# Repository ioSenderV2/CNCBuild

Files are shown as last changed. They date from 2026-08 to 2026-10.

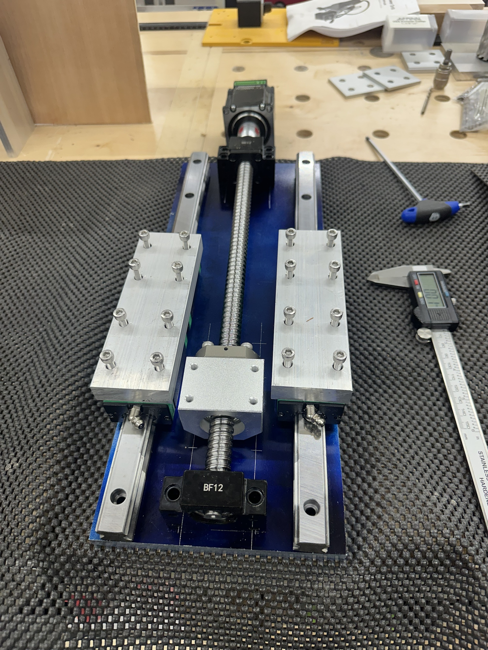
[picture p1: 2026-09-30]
machine/photos/z-carriage-assembly-end.jpg

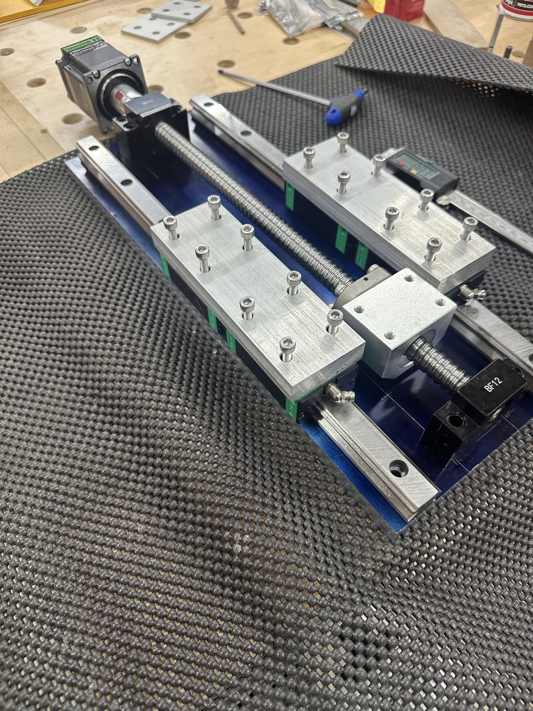
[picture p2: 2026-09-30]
machine/photos/z-carriage-assembly-oblique.jpg

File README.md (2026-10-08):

# CNCBuild

The machine, and everything about building, wiring, configuring and instrumenting it. Gantry beams are
**stacked pairs of 8020 `30-6060`** on HGR20 rails and 1605 ball screws.

Written down because these facts kept getting re-derived in conversation - travels, plate dimensions,
what shares a drag chain, which stored setting disagreed with the machine. A firmware fork's scratch
folder was the wrong home for them.

| Folder | What is in it |
|---|---|
| [`machine/`](machine/) | The build itself: extrusions, rails, screws, plates, and the mechanical decisions with their reasons |
| [`linear-encoder/`](linear-encoder/) | Magnetic linear scales + AS5311 + ESP32-S3 → CAN → grblHAL. The most developed subsystem; design complete, nothing built |
| [`commissioning/`](commissioning/) | Measurements taken **from the machine** - travels, squaring, tape extents. The authority when the config disagrees |
| [`wiring/`](wiring/) | How the boxes connect - the DB37 between the controller box and the remote axis breakout box |

## Generated views - regenerate, never edit

Three files are built from the prose rather than maintained beside it, because a
hand-maintained summary drifts from what it summarises. That is not hypothetical here: on
2026-10-02 two settled decisions were relitigated, both because a pointer had gone stale.

| Build it with | What you get |
|---|---|
| `python tools/status.py all` | [`STATUS.md`](STATUS.md) - every open item, harvested from the ✅ ⚠️ 🔴 ❌ markers in the prose. [`INDEX.md`](INDEX.md) - every heading in the repo |
| `tools\make-pdf.ps1` | **`build-document.pdf`** - the whole mechanical design as one printable file: the thirteen `machine/*.md` files in reading order, a clickable contents, all fifteen photographs embedded with their captions, and links into the shop pack. ~4.4 MB, 97 pages. **Untracked** - rebuild it, do not commit it |

**If a generated file and a `.md` file disagree, the `.md` file wins** and the generated copy
is stale. The PDF needs two packages - `python -m pip install markdown pillow` - the first to
render the prose, the second to scale the photographs to print size on the way in (22.9 MB of
originals become 4.4 MB of PDF, still over 300 dpi at the size they are printed; the originals
in `machine/photos/` are never touched). `status.py` is stdlib-only on purpose, because it
gates correctness and the PDF does not.

## What lives elsewhere

| | Where | Why |
|---|---|---|
| grblHAL firmware + the CAN plugin | `stevenrwood/iMXRT1062`, branch `srw/local-build-config` | It is firmware and needs that build tree |
| ioSender (the sender application) | `ioSenderV2/ioSender` | Its own product |

## A standing rule for this repo

**The machine is the authority, not the configuration.** `$130` once read 889 mm against a real 860 mm,
because a catalog preset overwrote a measured value - which quietly cost soft-limit protection until it
was found by accident. Anything in `commissioning/` is measured; anything quoted from a config file is
labelled as such.

Datasheets are **committed, not linked**. The ESP32 module's header pinout was extracted once, lost, and
had to be recovered from a schematic - and both of that vendor's URLs refuse a plain fetch. A link is not
a copy.

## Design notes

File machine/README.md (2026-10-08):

# The machine

The build itself: extrusions, rails, screws, plates, and the mechanical decisions with their reasons.
Measured values belong in [`../commissioning/`](../commissioning/).

## 🔴 Two documents, split by register - read this first

**[`assembly.md`](assembly.md) says what gets built. The thirteen chapters say why.** Keep them apart.
A page that carries both is arguing with itself while somebody is holding a drill, which is how one
unusable document came about in the first place.

| | Source | Printout | What belongs in it |
|---|---|---|---|
| **The build document** | [`assembly.md`](assembly.md) | `build-document.pdf`, ~18 pages | Parts, hardware, what bolts to what, in the order it is done. Imperative. No reasoning, no options weighed, no figure's history |
| **The design record** | the thirteen chapters below | `design-record.pdf`, ~102 pages | Why the machine is that shape. The schemes that were tried and killed, the figures that moved and when, every ⚠️ and 📌. Reference, never worked from |

📋 **`tools\make-pdf.ps1`** from the repo root builds both. `-Doc build` or `-Doc record` for one.
Both are derived and untracked: **if either disagrees with a `.md` file, the `.md` file wins.**

🔴 **A new decision goes in a chapter, and then into `assembly.md` if it changes what gets built.**
Writing the reasoning into `assembly.md` is the failure this split exists to prevent.

| File | What is in it |
|---|---|
| [`assembly.md`](assembly.md) | **How the machine goes together.** Every part, its hardware, and the order of work - mill trip, beams, Y ends, X gantry, Z, spindle, stand-and-measure, box, sand |
| [`gantry-beam-joint.md`](gantry-beam-joint.md) | Each gantry beam is two stacked 8020 `30-6060`. How they are tied together, and the four schemes that were killed getting there |
| [`torsion-box.md`](torsion-box.md) | What the machine stands on. The box, its three cedar posts, the base frame and shear walls, and the transport plan |
| **The ten plate files** | What holds the beams up and what hangs off them — listed below |
| [`drawings/`](drawings/) | **Derived, not authoritative.** The shop pack for the machining trip - one sheet per plate, printable to PDF. If a sheet and a file above disagree, **the file wins** |

## The plates, risers and the spindle mount

**Partly settled.** The beams themselves are finished — see
[`gantry-beam-joint.md`](gantry-beam-joint.md). These ten files cover what holds them up and what
hangs off them. Several dimensions are still **⚠️ Open** and are marked as such rather than guessed;
[`open-items.md`](open-items.md) is the generated-adjacent list of them, and the repo-wide one is
[`../STATUS.md`](../STATUS.md).

They were one 2877-line file, `end-plates-risers-and-spindle.md`, until 2026-10-02. The split is
verbatim — no decision was reopened in the move — and it is along the seams the prose already had.

📋 **These thirteen are the design record**, printed by `tools\make-pdf.ps1` as
`design-record.pdf` — in reading order, with a clickable contents and every photograph embedded
beside the chapter that cites it. **To carry something to the machine, carry `build-document.pdf`
instead** — see the two-document note at the top of this file.

| File | What is in it |
|---|---|
| [`loads-and-plate-thicknesses.md`](loads-and-plate-thicknesses.md) | **Read this first.** The cutting-force recalibration (500-1000 N, not 250) that **every deflection figure in this repo depends on**, the plate and riser thicknesses it sets, and the one measurement that would settle the 1/4" question |
| [`y-beam-support.md`](y-beam-support.md) | How each Y beam is held at its ends: the end plate / Z riser, the **cast stepper frames** on all four axes, the thrust block, the inverted ball nut and its sole plate, and BF12 at the rear |
| [`lateral-stiffness.md`](lateral-stiffness.md) | The lateral fix — tapered front fins per beam, the **one 1210.73 mm steel back plate** replacing both rear risers and the shear panel, and the tongues that back them |
| [`outboard-plate.md`](outboard-plate.md) | The full-height outboard plate: **10 gauge steel**, also the Y back joining plate, how it lands on the torsion box, the galvanic cost, and the encoder tape that runs on the front plate |
| [`spindle-and-mount.md`](spindle-and-mount.md) | The Ø80 2.2 kW water-cooled spindle, its body dimensions, why not 3 kW, and the 109 mm offset from the X beam to its centreline |
| [`stepper-sizing.md`](stepper-sizing.md) | **2.2 N·m NEMA 23 on all four axes**, and why neither 1.5 nor 3.2 — thrust is a non-term on a 5 mm lead, the screw and the rotor are the inertia, and the real ceiling is the **measured 930 mm** span's whip at 1510 rpm |
| [`z-carriage.md`](z-carriage.md) | The 164 × 175 × 1/2" Z plate, the spacer blocks and why they get skimmed, the clamp mount geometry, the travel budget and the top stop |
| [`x-gantry-end-plates.md`](x-gantry-end-plates.md) | The two X gantry end plates: the vertical stack-up, the 242.5 mm height, the sole plate and doubler block, the four bolts above the Y beam top, and the shelf |
| [`tramming.md`](tramming.md) | Roll by **shimming the shelf**, nod still open, and why the carriage plate joint is deliberately not adjustable |
| [`machining.md`](machining.md) | **One trip, so design ahead of the build.** One WCS origin per plate, one reference rail, and what mating hardware to take |
| [`open-items.md`](open-items.md) | Everything still unmeasured, grouped by where it came from |

## Frame and motion

| | |
|---|---|
| Beams, all three axes | **Two 8020 `30-6060` stacked** — 60 mm wide × 120 mm tall, **1000 mm** long |
| Rails | **HGR20**, one per profile, 17 × M5 at 60 mm into T-nuts. **Y rails are on the beams' inside faces, facing each other.** X, Y1 and Y2 share one kit; **Z is a 400 mm kit from a different supplier** - do not quote one kit's dimension for the other |
| Bearing blocks | **77.09 mm** each, measured - two butted read **154.18 mm**, which is what sets the 154 mm plate width. Of that, only the **51.15 mm machined pad** bears; a butted pair spans **128.24 mm** of pad, and that is the real floor for any carriage plate |
| Ball screws | **1605**. **Every axis drives through a cast stepper frame** — X, Y1, Y2 and Z — carrying motor face, bearing housing and coupler in one part, which is what retired the M5 standoffs. BF12 stays at each far end. Y ball nuts run **inverted**, on a tongue off the bottom of the carriage plate, so their bolts are reachable at assembly |
| Ball screw position | **X on top** (preserves vertical milling height); **both Y underneath** (Y1's top must stay clear for the X stepper) |
| Y steppers | **At the FRONT of the machine** (2026-10-02) — one cast frame carries motor face, bearing housing and coupler |
| Steppers | **2.2 N·m, NEMA 23, on X, Y1, Y2 and Z** — one type, so one spare covers every axis. Not 3.2: no thrust is needed and a higher-inductance motor in the same frame is worse above ~1200 rpm, which is where the rapids live. See [`stepper-sizing.md`](stepper-sizing.md) |
| Y beams | **Do not move** — their end plates bolt to the torsion box |
| Y axis assembly mass | **37 lb** each, before the joining plates |
| Spindle | **Ø80 mm, 2.2 kW water-cooled** with matching VFD, on two 80 mm clamps |
| Y beam support | **Front:** a tapered 100→200 mm × 302 mm × 1/2" plate per beam, with a 60.5 × 50 window for the stepper frame. **Rear:** one **1210.73 mm × 12" × 1/4" A36 steel** plate for both beams. Ends only — the ball screw runs under the beam |
| **Plate height** | 🔴 **The five plates that stand on the box are all 301.625 (11 7/8") high** — two side plates, the back plate, two front fins — and **every hole on them is measured from the bottom edge**, the edge that bears on the box's top skin. One height plus one reference edge is what lines the beam up without any plate knowing about another. **A part that is not 301.625 is misordered or mismade.** PLATE_H in the registry; the other three symbols derive from it so they cannot drift |
| Plate materials | 6061 throughout **except** the two Y outboard plates (**10 gauge steel**) and the Y rear plate (**1/4" A36**) — see [`loads-and-plate-thicknesses.md`](loads-and-plate-thicknesses.md), [`outboard-plate.md`](outboard-plate.md) and [`lateral-stiffness.md`](lateral-stiffness.md) |

**Axes:** X, plus a ganged **Y1 (Y) / Y2 (A)** pair, plus Z. `Y_GANGED` + `Y_AUTO_SQUARE` in the
firmware config, so the second Y motor is M3.

### End plates

Partly specified - see [`y-beam-support.md`](y-beam-support.md) and
[`lateral-stiffness.md`](lateral-stiffness.md). They bolt the Y beams to the torsion box.

🔴 **Reworked 2026-10-02 and all four as-built Y risers are scrapped.** Cast stepper frames replaced
BK12 and the M5 standoffs, the Y steppers moved to the front, and the two rear risers became one
1210.73 mm steel plate that is also the rear shear panel. Four measurements gate cuts that cannot be
undone — see [`open-items.md`](open-items.md) before ordering or cutting anything for the Y ends.

**Deferred, not blocking: the 35 mm sensor bore.**
[`../linear-encoder/design-can-position-feedback.md`](../linear-encoder/design-can-position-feedback.md)
§ "The sensor mount" reads as though each endplate and the X gantry plate **already has a 35 mm
hole**. That was written against plates that existed; on this build **nothing has been drilled**.

So it is not a conflict to resolve - it is simply a **feature to include when these plates are
designed**, and the encoder design's wording will want a light touch once they are. Carry it as an
input to the end plate design, not as an open question.

## Cable routing

The two gantry-end encoder cables run **inside the extrusion**, then through the **drag chain** -
which also carries **the spindle cable** and the stepper cables.

**The spindle cable is the first thing to move if anything looks wrong.** A VFD lead is the worst
emitter on the machine and in the chain it runs parallel to the encoder cables for their whole
length. The route is already chosen: overhead, with the coolant and air lines. This is written down
because the failure signature is counts drifting over hours, which reads exactly like lost steps and
sends you to the mechanics instead of the cable.

Drag chain brackets bolt **through the back joining plate** into T-nuts in the outer slots - see
[`gantry-beam-joint.md`](gantry-beam-joint.md).

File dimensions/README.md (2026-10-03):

# Dimensions

**A convention change, made deliberately on 2026-10-02, and a bigger one than the drawings folder.**

[`registry.toml`](registry.toml) is **authoritative for values.** The `machine/*.md` files stay
authoritative for **reasoning**. If a number here and a number in prose disagree, **this folder wins
and the prose is stale.**

That inverts the previous rule, under which the `.md` files were the source of truth for everything.
It is a narrower inversion than it sounds: the registry owns only *what a number is*, and prose keeps
owning *why* — what it trades against, what was rejected, what it would cost to change. Nothing about
how the files read has to change.

## Why

On 2026-10-02 a single session found **five wrong numbers** in the prose. They were two different
faults, and only one of them is fixed by writing numbers down in one place.

**Three were bad primitives carried as labels.** A "5/8in" spacer that measured **16.41**; a
"Φ80×200" spindle whose nameplate reads **213**; a "1/2in" plate whose stock is **10 mm**. In every
case the repo had recorded what the part was *sold as* and then used it as a dimension.

**Two were orphaned derivations**, and these are the dangerous class:

| | |
|---|---|
| The shelf's rear bolt | dimensioned from the **beam front**. The beam moved to flush; the hole did not, and it now lands at Y 0 — off the edge of the plate |
| "1.8 mm proud" | computed from an M8 column at **20**. The column was corrected to 35 elsewhere in the same file, and the consequence was left behind |

**A symbol would not have caught either.** A number in prose is just text; nothing checks it. What
catches them is the **reverse index** — change a primitive, and the tool lists every value that has
to be re-derived. That is what `expr` is for and why the registry is machine-readable rather than a
markdown table.

## Use

Run through [`../tools/dims.py`](../tools/dims.py). Stdlib only, Python 3.11+.

| Command | |
|---|---|
| `dims.py check` | evaluate everything; non-zero exit on any error. Also lists what is **not confirmed on the real part** |
| `dims.py deps SYM` | **what depends on SYM, transitively. Run this BEFORE changing a primitive** |
| `dims.py open` | every OPEN or nominal value, and what each feeds |
| `dims.py table` | every symbol, value, provenance |
| `dims.py fusion` | Fusion 360 parameters CSV |
| `dims.py md` | regenerate [`VALUES.md`](VALUES.md) |

## Provenance is not decoration

It is the repo's standing rule — *the machine is the authority, not the configuration* — made
machine-readable.

| | |
|---|---|
| `measured` | off the real machine or part, with an instrument |
| `part` | off a part's own geometry that is not in doubt |
| `vendor` | off a datasheet committed to `manufacturer-assets/` |
| `nominal` | ⚠️ a catalogue figure **not yet confirmed on the part** — the class that produced three of this session's five errors |
| `derived` | computed here from other symbols |
| `OPEN` | 🔴 not established. **A placeholder. Must not be cut to.** |

## Fusion

`dims.py fusion` writes [`fusion-parameters.csv`](fusion-parameters.csv) for **Modify → Change
Parameters → Import**.

⚠️ **Verify the first import rather than trusting it.** Fusion has shipped variations on whether it
wants a header row; `--header` adds one if yours does.

🔴 **Every symbol exports as a plain number, never as its expression.** Fusion would accept the
expression, but then two systems would own the same derivation and they would drift — which is the
exact failure this registry exists to stop. **The registry derives; Fusion consumes.** Re-export and
re-import after any registry change, because Fusion holds a copy and a copy goes stale.

## What this does not do yet

⚠️ **Nothing enforces that a number quoted in prose matches the registry.** `deps` tells you what to
go and check; it does not check it for you. A prose checker — tagging quoted numbers so they can be
verified mechanically — is the obvious next step and is **not built**.

⚠️ **Only the ten plate files split out of `end-plates-risers-and-spindle.md` on 2026-10-02
have been mined for primitives** - see [`../machine/README.md`](../machine/README.md) for the list.
The other `machine/*.md` files have numbers that are not in here.
Key them in as they get touched rather than attempting a sweep, which is the version of this job that
gets abandoned half-done.

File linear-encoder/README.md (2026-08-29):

# Linear scale position feedback

Magnetic linear scales on each axis, read by AS5311 sensors, decoded to positions by an ESP32-S3, sent
over CAN to the Teensy, so grblHAL knows where each axis **actually** is. Status: **design only, nothing
built.**

| File | What it is |
|---|---|
| **[`design-can-position-feedback.md`](design-can-position-feedback.md)** | **Start here.** The whole design: scope, the sensors, the machine's layout, staleness, the CAN frame, grblHAL integration, failure modes, phasing, and the wiring (§14). |
| [`controller-board.md`](controller-board.md) | The 4-jack daughter board that sits over the ESP32 module: the no-magnetics rule, the mechanical envelope, and the 5 mm-pin / 14 mm-standoff problem. |
| [`sensor-board.md`](sensor-board.md) | The AS5311 board in the puck: what goes on each face, the passives, and the connector question the layout is waiting on. |
| [`hardware-esp32-s3-rs485-can.md`](hardware-esp32-s3-rs485-can.md) | The ESP32 module's 20-pin header map - **not documented on the Waveshare wiki**, only in the schematic. |
| [`kicad/controller-board/`](kicad/controller-board/) | KiCad project. Schematic drawn and verified against KiCad 10.0.5; **no layout yet**, and the symbols are placeholders to be swapped for real parts. |
| [`kicad/sensor-board/`](kicad/sensor-board/) | KiCad project. Schematic drawn and verified the same way; **no layout yet**, and the connector footprint is deliberately unresolved (see `sensor-board.md`). |
| [`../manufacturer-assets/`](../manufacturer-assets/index.html) | The AS5311 datasheet (rev 1.12) and the module schematic. **Untracked** - third-party documents in a public repo. The tracked `index.html` there records where each came from, including the browser-User-Agent trick both waveshare.com URLs need. |

The datasheets are **kept on disk on purpose**: the header map was extracted once, lost, and had to be
found again. A link is not a copy - but nor is someone else's document ours to republish, so the files
stay untracked and `../manufacturer-assets/index.html` records how to fetch each one.

## What is not here yet

- **Both PCB layouts.** Two schematics exist and both pass ERC, but nothing has been placed or routed,
  and every symbol is still a placeholder carrying the netlist rather than a real part.
- **The ESP32-S3 firmware**, and the grblHAL plugin at the other end of the CAN link.
- **The puck-mount mechanical drawings** - the 35 mm round, the 30 mm bore, and the anti-rotation
  fix that §1.4 leaves open.

An earlier note here said that when the first of these landed the work would probably want its own
repo, away from the firmware fork. That has happened: this **is** that repo.

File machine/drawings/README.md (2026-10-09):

# Drawings

**This folder is a convention change, made on purpose on 2026-09-30.**

Until now this repo had no drawings. The premise was that **the reasoning is the artifact** - prose
that says *why* a dimension is what it is survives a redesign, where a drawing does not. That premise
still holds for everything in `machine/*.md`, and those files remain the **source of truth**.

What forced the addition is the **one machining trip**. Prose cannot be taken to a mill. Two things in
particular are hard to carry in words and easy to get wrong later - the **riser geometry** and the
**three-point pad layout relative to the five legs** - and that was already flagged as a decision to
make deliberately rather than drift into.

## The rules this folder follows

- **Derived, never authoritative.** If a sheet and a `.md` file disagree, **the `.md` file wins** and
  the sheet is stale. Nothing is specified here for the first time.
- **Hand-authored SVG, inline in one HTML file.** No CAD dependency, no binary blobs, and it diffs.
  Print to PDF from a browser when a paper copy is wanted - the same route the Mega-XL build doc in
  the ioSender repo uses.
- **Unknowns are marked, never invented.** Amber rows are dimensions that do not exist anywhere in the
  repo. That is the repo's standing rule applied to drawings: an unknown stays unknown until it is
  measured.
- **One WCS origin per plate, absolute coordinates, never chained.** The mill is manual in X and Y, so the
  operator types coordinates and chained dimensions accumulate error.
- **Extrusion bolt patterns are scribed.** Two lines, four stations ticked along each.

## Files

| File | What it is |
|---|---|
| [`shop-pack.html`](shop-pack.html) | Four plate sheets plus a pre-trip checklist and pack list. Open in a browser, print to PDF |

## Status

**Regenerated through 2026-10-02**, after the Y end rework: cast stepper frames replaced BK12 and
the M5 standoffs, the Y steppers moved to the **front**, each Y beam end carries a tapered front fin, and
the two rear risers became one 1200 mm × 12" × 1/4" A36 steel plate that is also the rear shear
panel. Every sheet in the pack has been brought up to that design.

### What is in the pack

| Sheet | Part | Note |
|---|---|---|
| 1 | Front Y end plate / Z riser | Regenerated 2026-10-02 — the 100 → 200 taper on the 302 mm square, the 60.5 × 50 window, columns 35 / 65 |
| 2 | X gantry end plate | Regenerated. Only the **right-hand** plate carries the BF12 tongue, so the two are not interchangeable |
| 3 | X carriage plate | 154 × 407, untouched by the rework and still correct |
| 4 | Z plate | **164** × 175 — corrected from 154; at 154 eight M5 counterbores break through the plate edge |
| 5 | Y nut doubler and sole bracket | Added 2026-10-02 |

### ⚠️ Not drawn yet - two trip parts have no sheet

- **The cast stepper frame interposer** - 60 × 150 × 3/8" 6061, **quantity 3** (Y1, Y2 and the X stepper
  end), one drawing. Six M8 clearance into slide-in T-nuts at rows 82 / 110 / 138, six M5 tapped for
  the casting at bar coords 28-71, no counterbores. **Fully dimensioned in the prose and simply not
  drawn here.**
- **The 1200 mm rear plate** - 1200 × 12" × 1/4" A36 steel, one for both Y beams: the 16-bolt beam
  pattern, the 8-bolt box row at Y 30, and **BF12 face-mounted on 4 × M5** per beam.

### 📋 In progress: a 1/2" baltic birch mockup

Being cut while the mill visit is a couple of weeks out, **Sheet 1 first**. It settles the window's
height - the 50 mm is a budget and the casting projects only about 20 mm below the bar - and the
spindle clearance that gates the taper cut, which is one bandsaw pass and cannot be put back.

🔴 **Plywood is for fit, never for transfer.** Its thickness runs under 12 mm and varies, and an M5
threaded insert needs a far larger bore than a 4.2 mm tap drill - so anywhere the design has fought
for edge distance or web, an insert will not sit where the real hole does. **A plywood plate must
never go to the mill as a template**: this folder is derived-never-authoritative, and a physical part
is far more persuasive than a sheet.

### What still gates drilling

⚠️ **No plate in this pack has a complete hole schedule yet**, and that is the pack's main finding.
What it does have is every dimension the repo actually holds, with the gaps named - which turns
"design ahead of the build" from an instruction into a list. Two questions gate cuts that cannot be
undone, and each needs a part or the mill in front of you - see
[`../open-items.md`](../open-items.md):

1. How far past the front riser plane the spindle reaches, and whether it fouls the widened fin at
   low Z
2. The mill's model, and whether its DRO is 2-axis or 3-axis

📌 **The merged build document exists now** - `tools\make-pdf.ps1` builds `build-document.pdf`, the
thirteen `machine/*.md` in reading order with every photograph embedded. It links to the sheets here by
their anchors. It does **not** contain them: the pack is regenerated on its own cycle, and that is
deliberate.

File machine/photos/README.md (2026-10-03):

# Photographs of the build

**A deliberate addition to this repo's conventions, 2026-09-29.** Until now the premise was that the
reasoning is the artifact and source means KiCad plus Python - there were no images here at all.
That premise held right up until it didn't.

## Why these exist

The gantry joint design turned on a fact **no drawing shows**: behind the 2.21 mm skin at the centre
of each `30-6060` face there is nothing. The 8020 cross-section drawing is dimensionally complete and
still led to the wrong conclusion, because a rib was inferred where there is void. Three bolting
schemes were designed and killed on that single observation, and it came off a photograph and an eye
down the end of a real extrusion.

Two things follow, and they are the rule for adding anything here:

1. **A photograph is admissible evidence in this repo when it shows something a drawing cannot.**
   Cross-sections, clearances, what is actually bolted to what, a part that disagrees with its
   catalog entry.
2. **It is not a substitute for a measurement.** Nothing here should be scaled off. Every number in
   the prose came from a caliper or a vendor drawing, and stays labelled that way - see the standing
   rule in the [root README](../../README.md).

These are photographs of **this build**, taken by the owner. Third-party material - vendor drawings
and datasheets - goes to [`../../manufacturer-assets/`](../../manufacturer-assets/) instead, where it
is deliberately untracked because this repository is public.

## What each one shows

| File | What it is evidence of |
|---|---|
| `gantry-stack-end-view.jpg` | The two `30-6060` stacked, end on. The butt joint with nothing mechanical across it - the problem the joining plates solve |
| `gantry-stack-end-view-bk12.jpg` | Same, closer, with the BK12 support in place. **The clearest view of the internal voids** and of the corner bores running lengthwise |
| `gantry-stack-rails-front.jpg` | 1000 mm, one HGR20 rail on the front face of each profile. Shows why the spindle's rail couple crosses the seam |
| `gantry-stack-ballscrew-front.jpg` | The 1605 screw with BK12 / BF12 supports, mounted above the stack on X |
| `front-plate-trial-single-bolt.jpg` | Trial plate in the gap between bearing blocks, establishing that the two slots flanking the seam are reachable |
| `front-plate-trial-flange-bolts.jpg` | **The clearance test that settled the front plate.** Four M8 flange bolts seated in the 46.7 mm gap, blocks clearing - after arithmetic had said they would not fit |
| `z-carriage-assembly-end.jpg` | Z carriage dry-assembled on the **X carriage plate** - HGR20 rails on it, the spacer blocks (**16.41 mm measured**, not the 5/8" this repo used to call them) sandwiched on the bearing blocks, ball nut housing between them (shown dry-fitted, without the Z plate that finally clamps them). The blue is **layout dye**, not a finish |
| `z-carriage-assembly-oblique.jpg` | Same, oblique - shows BK12 with motor and BF12 both on the plate, so screw and motor are fixed relative to it |
| `y-beam-end-plate-outer.jpg` | **A Y beam as built.** End plate / Z riser on the stacked pair, bolt heads on the outer face, fully exposed - the arrangement the X end plates copy |
| `y-beam-stepper-mounted.jpg` | Stepper on the outside of the riser, shaft through the plate. The riser runs well below the beam |
| `y-beam-coupler-bk12.jpg` | Coupler between motor and screw, BK12 inboard, screw running under the beam |
| `y-beam-riser-and-gusset.jpg` | The riser with the existing **12" × 6" × 1/4" gusset** on the outboard face |
| `y-bearing-blocks-butted-154.jpg` | **Calipers reading 154.18 mm across two HGH20 blocks butted** on the X/Y kit's rail. The measurement that confirmed the X end plate width and killed the "2-3 mm between the blocks" this repo had carried as its reason for it |
| `y-bearing-blocks-machined-pads-128.jpg` | **128.24 mm across the two blocks' machined pads only.** The pair with the end caps excluded - which is what actually bears, and the number any carriage plate has to exceed. Pads are 51.15 each, end caps 12.97 |
| `front-fin-template-tongue-bolts.jpg` | The 1/4" MDF front-fin template, bottom corner. **The Y 30 line with T1 and T2 marked at X 25 and 170** - the check that closed the fin's geometry, against an outline whose taper is not corner-to-corner. The 7 / 46 / 7 and 28 / 58 / 73 pencil marks are the cast stepper frame's bolt pattern, laid out separately |
| `casting-with-interposer-mockup.jpg` | **The cast stepper frame with an aluminium bar standing in for the 3/8" interposer, shown inverted on the bench.** ⚠️ **In the machine this hangs**: six M8 into T-nuts hold the bar up under the Y beam, and the casting is bolted up into the bar, hanging from its own bolts. Nothing rests on anything. What the photograph shows is the **stepped foot** and the **overhang past the bar's end** — which is why the bar continues through the front plate's 60.5 × 50 window and is the higher of the two parts in it. A combination square is set against the casting's body; the prose carries that height as **27**, from the owner, not scaled off this image |

`front-plate-trial-flange-bolts.jpg` is worth keeping for its own sake: the calculation said
47.3 mm against a 46.7 mm gap and the parts said otherwise. The parts were right.

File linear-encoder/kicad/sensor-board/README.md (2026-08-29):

# Sensor board - KiCad

Schematic for the board described in [`../../sensor-board.md`](../../sensor-board.md).

| File | |
|---|---|
| `sensor-board.kicad_sch` | The schematic. Symbols are **embedded** (`lib_symbols`), so it needs no external libraries. |
| `sensor-board.kicad_pro` | Project wrapper. |
| `netlist.txt` | The connection list, generated from the same source as the schematic. |
| `generate.py` | The seed that produced the first version. See the warning below. |

> 🔴 **`generate.py` is already a SEED, not the source of truth - as of 2026-08-29.**
> It took one `kicad-cli sch erc` run: the tool **re-saves the schematic**, upgrading it from the
> `version 20231120` header the script writes to KiCad 10's own format (and to CRLF, which
> `.gitattributes` normalises back to LF on commit). Nobody opened Eeschema; running the checks was
> enough. **Re-running `generate.py` now overwrites whatever KiCad wrote, including any layout or
> hand edits.** Treat the `.kicad_sch` as the live document, keep the script as the record of how the
> netlist was derived, and if the design changes, edit in Eeschema and update `netlist.txt` to match.
>
> Connectivity was re-checked **after** the upgrade: all 12 nets and every node still identical, and
> all 9 `no_connect` markers intact. The format change carried the design across without loss.

## Status: verified against KiCad 10.0.5

Checked with `kicad-cli`, not just written and hoped for:

| Check | Result |
|---|---|
| Parses / loads | **Yes** - `sch erc` and `sch export netlist` both succeed |
| Netlist matches `netlist.txt` | **Exactly.** All 12 connected nets, every node identical, nothing extra or missing |
| `no_connect` coverage | **9 pins - 1, 6, 7, 10, 11, 15, 16, 17, 20** - exactly the datasheet's NC list plus Index and PWM |
| ERC violations | **12**, all one warning type - see below |

Reproduce with:

```
kicad-cli sch erc --severity-all --output erc-report.txt sensor-board.kicad_sch
kicad-cli sch export netlist --format kicadsexpr --output kicad-export.net sensor-board.kicad_sch
```

### The 12 violations are all expected

Every one is `lib_symbol_issues`: *"The current configuration does not include the symbol library
'cnc'"*. The symbols are embedded in the file rather than coming from a configured library, so KiCad
notes it. Nothing is broken - and as on the controller board the warning is arguably useful, because
those symbols **are** placeholders.

## Symbols are placeholders - swap before layout

`cnc:AS5311`, `cnc:RJ45_8_UNSHLD`, `cnc:TVS_4`, `cnc:R`, `cnc:C`, `cnc:TP` are minimal rectangles with
correct pin numbering and, on the AS5311, correct pin names from datasheet Table 1. Enough to carry
the netlist; not real parts. Before layout:

- **The RJ45 footprint is the open question, not a detail.** Unshielded, vertical, no magnetics - and
  whether it can be through-hole at all is unresolved. `../../sensor-board.md` has the height budget
  and the options. **Do not lay this board out until that is settled**, because it decides the part.
- **The AS5311 footprint is the one dimension that matters.** The datasheet's recommended land
  pattern is A 7.00, B 5.00, C 0.38, D 0.65, E 6.23 mm (rev 1.12 §9.1, Fig 18). What actually decides
  accuracy is the **Hall array position relative to the mounting datum**, from Figure 14 - and that
  figure was read off a rendered page, so confirm the reference edges first.
- Expect a "no power source" ERC complaint once real power symbols are used: `+3V3` arrives through
  a passive connector pin, which is honest for a board at the end of a cable. A `PWR_FLAG` settles it.

## How it is drawn

**Connections are by net label on a short stub at each pin**, not point-to-point wires - the same
convention as the controller board, for the same reason. It reads as a fan-out list, which is what
the board is.

Net names ending `_SRC` are the chip side of a series resistor; the bare name is the cable side. So
`A_SRC` is `U1` pin 4, `A` is what reaches the jack.

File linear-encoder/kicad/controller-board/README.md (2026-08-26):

# Controller board - KiCad

Schematic for the daughter board described in [`../../controller-board.md`](../../controller-board.md).

| File | |
|---|---|
| `controller-board.kicad_sch` | The schematic. Symbols are **embedded** (`lib_symbols`), so it needs no external libraries. |
| `controller-board.kicad_pro` | Project wrapper. |
| `netlist.txt` | The connection list, generated from the same source as the schematic. |
| `generate.py` | **The seed that produced the first version - not the live source any more.** See the warning below before re-running it. |

> 🔴 **`generate.py` is now a SEED, not the source of truth.**
> The schematic has since been **opened and re-saved by KiCad 10**, which upgraded the file format and
> may carry hand edits and layout work. **Re-running `generate.py` overwrites all of that.** Treat the
> `.kicad_sch` as the live document from here on; keep `generate.py` only as the record of how the
> netlist was derived, and if the design changes, edit in Eeschema and update `netlist.txt` to match.

## Status: verified against KiCad 10.0.5

Opened and checked with `kicad-cli`, not just written and hoped for:

| Check | Result |
|---|---|
| Parses / loads | **Yes** - `kicad-cli sch erc` and `sch export netlist` both succeed |
| Netlist matches `netlist.txt` | **Exactly.** All 15 nets, 0 mismatches, no extra or missing nodes - re-checked after KiCad re-saved the file, so connectivity survived the format upgrade |
| ERC violations | **22**, all one warning type - see below |

Reproduce with:

```
kicad-cli sch erc --severity-all --output erc-report.txt controller-board.kicad_sch
kicad-cli sch export netlist --format kicadsexpr --output kicad-export.net controller-board.kicad_sch
```

### The 22 remaining warnings are expected

All are `lib_symbol_issues`: *"The current configuration does not include the symbol library 'cnc'"*.
The symbols are embedded in the file rather than coming from a configured library, so KiCad notes it.
Nothing is broken - and the warning is arguably useful, because those symbols **are** placeholders.

An earlier run had 134 violations. The other 112 were real and are fixed:

- **107 x `endpoint_off_grid`** - placement origins were not multiples of 1.27 mm, so every pin and
  stub sat off the connection grid. Connections still resolved, but off-grid endpoints can silently
  fail to connect once a human edits the sheet. `generate.py` now snaps origins.
- **5 x `pin_not_connected`** - header pins 2 (5V), 5/7 (UART) and 6/8 (USB), which are deliberately
  unused. Now carry `no_connect` markers, which turns an error into a recorded decision.

## How it is drawn

**Connections are by net label on a short stub at each pin**, not point-to-point wires - electrically
identical for netlist and ERC purposes, and far less error-prone to generate than routing 40-odd nets
by computed coordinates. It reads as a fan-out list rather than a picture of wires, which is what the
board actually is.

## Symbols are placeholders - swap before layout

`cnc:RJ45_8`, `cnc:HDR_2x10`, `cnc:R`, `cnc:C` are minimal rectangles with correct pin numbering:
enough to carry the netlist, not real parts. Before layout, replace them with manufacturer symbols and
footprints - in particular:

- the RJ45: **shielded, NO integrated magnetics** (see the warning at the top of `controller-board.md`);
- the 2x10 header: **2.00 mm pitch**, not 2.54 mm.

`J1..J4` are X, Y, A, Z in that order; `J5` is the header to the module's `P1`.

Expect a "no power source" ERC complaint once real power symbols are used - 3V3 arrives through a
passive header pin, which is honest for a daughter board. A `PWR_FLAG` on `+3V3` and `GND` settles it.

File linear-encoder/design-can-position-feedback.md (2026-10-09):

# Linear scale position feedback over CAN

**Status: design only, parked 2026-08-21; sensor + module pinouts added 2026-08-25.** Nothing is built. Resume when there is CAN hardware to
connect to. Written while the details were fresh so the next session starts from the reasoning rather
than re-deriving it.

---

## 1. What this is

Magnetic linear scales on each axis, read by Hall sensors, decoded to positions by an ESP32, sent over
CAN to the Teensy, so grblHAL knows where each axis **actually** is rather than only where it commanded
the axis to go.

```
  4 mag tapes + 4 Hall readers          X, Y1, Y2, Z
            |
            |  A/B quadrature pairs
            v
   ESP32-S3-RS485-CAN module            PCNT decodes A/B in hardware
            |                           (see §1.1 - the counters are only 16-bit)
            |
        CAN bus  (differential, noise-tolerant - the reason the ESP32 sits near the machine)
            |
            v
   Teensy 4.1 / T41U5XBB  -> grblHAL plugin -> ? status report -> ioSender
```

Four tapes and four readers, matching the motor configuration: X, **Y1, Y2** (the ganged pair), Z. Two
tapes on the gantry is deliberate - see §3 and §11.

### 1.1 ESP32-S3 PCNT: exactly enough, and it wraps

The ESP32-S3's pulse counter has **4 units**, each with two channels. Quadrature uses both channels of
one unit, so four units is exactly four axes with **no spare**. Adding a fifth scale later means a
different decode strategy, not another unit.

Each unit's counter is **16-bit signed**, wrapping at ±32767 counts:

| Scale resolution | Counter wraps every |
|---|---|
| 1 µm | **32.7 mm** |
| **1.95 µm — the actual AS5311 figure (§1.3)** | **63.9 mm** |
| 5 µm | 163 mm |

The overflow/watchpoint interrupt must accumulate into a wider software total. "Decoded in hardware" is
true of the quadrature but **not of the range** - a 400 mm axis folds back on itself a dozen times at
1 µm. The failure looks like a plausible position, not an obvious fault, which is what makes it worth
writing down.

### 1.2 The module's pins

**[`hardware-esp32-s3-rs485-can.md`](hardware-esp32-s3-rs485-can.md)** - the 20-pin header map, what the
board already uses, and where the schematic is kept. Short version: the header exposes
**IO3-IO14 free** (12 pins, and the encoders need 8), CAN sits on IO15/IO16 and RS485 on IO17/IO18/IO21,
so an encoder harness cannot collide with the bus.

Worth knowing before going looking: **the wiki does not document the header's GPIOs at all** - only the
4-pin SH1.0 connector. That map is in the schematic and nowhere else, which is why it reads as missing.

### 1.3 The sensor: AS5311

Identified 2026-08-25. Datasheet in [`manufacturer-assets/`](../manufacturer-assets/index.html) - `AS5311-Datasheet.pdf`
(rev 1.12). Everything here is from it; wiring is §14.

| | |
|---|---|
| Incremental resolution | **1.95 µm/step** (10-bit / 2 mm pole pair) = 512 steps/mm, 1024 edges per pole pair |
| Absolute (SSI/PWM) resolution | 0.488 µm/step (12-bit / 2 mm pole pair) |
| Max speed, incremental incl. interpolation | **650 mm/s** (39 m/min) - far above any feedrate here |
| System propagation delay, incremental | **384 µs** |
| Internal sampling rate | 10.42 kHz typ (9.38-11.46 over temperature) |
| Hysteresis, incremental | 2 LSB = 3.9 µm |
| Transition noise | 0.6 µm RMS (1σ) |
| INL / DNL | ±5.6 µm (25 °C, ideal magnet) / ±0.97 µm, no missing codes |
| Supply | 3.0-3.6 V **or** 4.5-5.5 V |
| Outputs | A (pin 4), B (pin 5), Index (pin 7); MagINCn (pin 2), MagDECn (pin 3) open-drain |

Consequences for what is already written here:

- **§1.1's wrap arithmetic uses the wrong resolution.** At 1.95 µm/step the 16-bit PCNT counter wraps
  every **±63.9 mm**, not the 32.7 mm the 1 µm row assumes. Still a dozen wraps on a 400 mm axis, so the
  overflow accumulator is no less mandatory - the table is just pessimistic.
- **§5's latency budget `T` starts at 384 µs** before the ESP32, CAN or the Teensy add anything. That is
  the floor, and it is measured, not estimated - which §11.4 asked for.
- **The 3.9 µm hysteresis and 0.6 µm noise set §5's threshold floor.** An alarm tighter than ~5 µm is
  alarming on the sensor's own quantisation.

#### The Index output is not a unique position

The AS5311 has an Index output, but it fires **once per 2 mm pole pair** - it repeats every 2 mm along
the tape. It is not a machine reference and does **not** solve §8's reboot/zeroing problem. Useful only
as a per-pole sanity check. Budget wiring for A and B, not A/B/Index (§14).

#### It does have a field-validity output - §11.1 is answered

Table 13 of the datasheet, decoded (both pins are open-drain, active low, "On" = asserted):

| Field | MagINCn | MagDECn | Meaning |
|---|---|---|---|
| GREEN (~10-40 mT) | Off | Off | Magnet OK |
| YELLOW (~3.4-54.5 mT) | **On** | Off | Still works, reduced accuracy |
| RED (<3.4 mT or >54.5 mT) | **On** | **On** | Out of range - not recommended |

So **`MagDECn` asserted ⟺ RED**, and a reader that has run off the end of its tape sees no field at all,
which is the `<3.4 mT` case. That makes the end-of-tape condition **detectable**, where §3 was written
assuming it could not be.

**This does not reopen §3.** The limit switches still stay - §3 lists three further reasons, each
independently sufficient, and none of them is about detectability. What changes is that the silent
failure becomes a reportable one: `MagDECn` goes straight into the `flags` byte (§6) and into §9's
failure table as a real signal rather than an inference.

### 1.4 Physical layout

Confirmed 2026-08-25. Three readers are mounted; the fourth is not solved.

| Reader | Mounted on | Reads | Cable run |
|---|---|---|---|
| 1 | X-axis endplate (one side) | **Y** scale | inside the gantry extrusion, then the drag chain |
| 2 | X-axis endplate (other side) | **A** scale (the ganged Y2 / M3) | inside the gantry extrusion, then the drag chain |
| 3 | back of the Z plate | **X** scale | up the Z plate - short, no chain |
| 4 | *not mounted* | **Z** - see §11.9 | - |

**The ESP32 lives at the top of the Z plate**, so it rides with the Z carriage and every cable terminates
there. That is what makes reader 3's run trivial, and it is what sets §14's 2.4 m figure for the two that
come off the gantry ends.

The pin budget in §14 is drawn for four readers. Three are wired today - 6 quadrature + 3 `MagDECn` = 9
of the 12 free pins - so the Z allocation is reserved, not spent.

#### The scales

**10 mm wide magnetic strip on a steel band, 3M PSA backing, 3 m in stock.** The steel band is the flux
return path - it is what makes the field readable at 0.3 mm - so an aluminium substrate is fine
everywhere; the tape brings its own ferrous backing.

**Laid flush with one edge, and that edge is what the tape is registered against.** Lateral alignment then comes from
machining rather than from eyeballing, and it fixes one dimension for the sensor mount: the magnetic
centreline is **5 mm in from the tape edge**, so the Hall array must sit 5 mm from the registration edge
and hold to ±0.5 mm (§1.3).

| Axis | Tape runs | Why |
|---|---|---|
| X, Y, A | down the **centreline between each pair of linear rails** | closest to the load path, so carriage pitch/yaw barely translates into position error |
| Z | on the **edge of the 1/2" (12.7 mm) aluminium Z gantry plate** | the 1605 ball screw occupies the space between the Z rails, so the centreline is not available |

**Bond the full length, not one end.** Steel expands at ~11.7 µm/m/K, aluminium at ~23.1. A tape anchored
at one end and left to float would report *steel's* expansion while the machine moves with *aluminium* -
roughly 110 µm per metre per 10 °C of divergence, which is precisely the size of error that trips a
lost-step alarm on a warm afternoon. Bonded along its length, the band is dragged by the substrate and
the scale tracks the machine's real thermal growth. This is a correct choice, not a compromise; do not
"improve" it into a one-end anchor later.

Handling, because the PSA is one-shot and the tape is a magnet: degrease with IPA, work above ~15-20 °C,
lay it down progressively rather than stretching it taut (a stretched PSA strip creeps back over days),
allow a day or two for full bond, and dry-fit and mark the ends before peeling anything. **Keep magnetic
bases, magnetic trays and magnetic sweepers off it** - a strong magnet can permanently corrupt the
magnetisation, and the result would look like a localised position error with no discoverable cause.

**Length budget: it fits, and not comfortably.** The tape is fixed to the extrusion and the sensor rides in the
plate's bore, so what a tape must span is **the range that bore sweeps** - not the extrusion length, not
the plate width. Every bit of end-of-travel dead zone is tape not bought — the plates stop well short
of the extrusion ends.

✅ **Closed 2026-10-09 - the travel is measured and the budget is real.** This table used to carry
upper bounds from the superseded Mega V XL geometry with a warning to re-derive it before cutting
tape. That is done.

**The travel is 820 mm, and it is the same on all three long axes.** Butted bearing blocks set the
carriage width on X and Y alike and every beam is 1000 mm, so there is one carriage length and one
rail length. The stops are the X end plates meeting the back plate or a front fin.

> **How it was measured, because the arithmetic is not obvious.** Put **one** bearing block at each
> end of the same rail, each pushed until its grease zerk touches the end plate, and measure the
> **inside** distance between them. That gap is the rail span less **two** block bodies — and the real
> carriage *is* two butted blocks (`BLOCK_BUTTED`, 154.18) — so the gap is the carriage's travel
> itself, not a proxy for it. The zerks are necessarily on the blocks' **outer** ends, since otherwise
> a pair could not butt, so the test reproduces the real stop geometry at both ends.
>
> Cross-check: rail-limited travel would be 1000 − 154.18 = **845.82**, so the end plates take
> **25.82** off, about 13 a side. The measurement is the figure; the derivation only confirms it is
> the right size.

| | mm |
|---|---|
| Travel, each long axis | **820** |
| Tape per long axis, 4 × 220 carrier sections | **880** |
| Overrun past each end of travel | **30** |
| X + Y1 + Y2 | 2640 |
| Z, on the same overrun rule | 295.91 |
| **Left of the 3 m roll** | **64.09** |

🔴 **The roll is the binding constraint on this whole layout, not the printer and not the beams.**
64 mm of margin on a **one-shot** PSA consumable is thin, and it is why the carrier sections stop at
220: at 230 the three beams come to 2760 and the roll goes negative once Z is counted. Anything that
grows — a longer travel on one axis, a more generous overrun, a wider Z allowance — comes out of that
64. **Buy more tape before changing any of them, not after.**

⚠️ **Z's 295.91 is the softest number here.** Its tape runs on the *edge* of the Z gantry plate
rather than between rails, and that axis has never been laid out — §1.4 calls its reader allocation
reserved rather than spent. `Z_TRAVEL` is firm; how much tape the edge mounting actually wants is not.

#### The overrun is not slop

Two independent reasons, and either alone would justify it:

1. **The datasheet forbids tape equal to travel.** Page 20 gives *maximum stroke = length of active
   area − length of Hall array*, the array being 2.0 mm, and "shorter poles at either edge of the
   magnet **must be excluded** from the active area". Usable stroke is therefore always less than the
   tape laid. ❌ **4 × 205 was considered and rejected** for exactly this: it gives 820, which *is* the
   travel, leaving nothing for the array, nothing for the end poles, and no tolerance at all on
   landing a four-section run by hand.
2. 🔴 **The hard stops are where the carriage ends up when something has gone wrong** — which is the
   worst possible moment for the reader to be off the end of its scale. A magnetic reader that leaves
   the tape and comes back gives a **wrong count and does not complain**. Tape past the mechanical
   stops costs nothing here.

At 30 mm a side the Hall array never approaches an end pole, so the end-pole exclusion stops being a
number anyone has to respect — it is simply never reached.

#### ⚠️ PROPOSAL - a printed carrier to lift the tape clear of the bolt heads

**Nothing here is built.** It is recorded because the reasoning is long, several blind alleys were
walked and closed on the way, and the alternative is re-walking them. **The tape-mounting text above
assumes the tape lies directly on the 45 mm front strip, which is what this would change.**

**The problem it solves.** The sensor puck needs `SENSOR_KEEPOUT_W` = 15 mm of clear lane, and the
strip's two bolt rows cannot move — they sit at ±15 from the seam because that is where the
extrusion's T-slots are. Going to a 13.8 mm flange head (`FLANGE_STRIP_D`) opened the lane to 16.2
and made the puck fit by **0.6 mm a side**, which the ø9 clearance holes' own ±0.5 of float can take
to 0.1. That is a *moving* clearance over a metre of stroke, and the way you discover it is by
destroying a sensor.

**The proposal.** A carrier strip between the rails, under the tape, thick enough that the puck rides
*over* the bolt heads instead of between them:

| | |
|---|---|
| Sections | **4 × 220 mm**, butted — the P1S bed takes four abreast in one run |
| Thickness | **4 mm**, which puts the chip face ~5.9–6.2 above the strip against 3 mm head crowns |
| Trench | **10 × 0.6 deep**, so the tape registers on both its own edges rather than a scribed line |
| Joints | **Loose keys in blind sockets**, not protruding tenons |
| Lateral location | **Scallops** at the seven bolt stations, the heads sitting in them |
| Bonding | **Continuous to the aluminium** — see below, this is not optional |

**Why loose keys and not a male/female dovetail.** A protruding tenon is swallowed at each joint, so
four sections would no longer reach 880. Blind sockets at both ends with a separate key keep every
piece a full 220. The joint's real job is **assembly** — self-aligning the sections into one straight
continuous trench while the adhesive cures — not structure; the aluminium underneath does that. Note
that a flat in-plane joint locks sideways and lengthwise but **not** vertically, and vertical is the
one the sensor feels, because vertical is air gap. Flatness has to come from the bond, not the joint.

**Why the scallops must locate in one direction only.** A semicircle matched to the head constrains
both axes, and seven of those along a metre, against holes each with ±0.5 of float in a ø9 clearance
hole, is an interference fit that will bow the strip. A **long straight-sided notch** running well
past the head locates laterally and slides freely lengthwise. Same register, no fight. What the
scallops buy beyond centring is width: the heads are only in the way *at* the stations, so between
them the carrier can run out toward the 45 mm block gap, which is more material around the trench and
far more bond area.

🔴 **Why the bond to the aluminium is the whole design, and why plastic was nearly wrong.** §1.4's
standing rule is *bond the full length* so the band is dragged by its substrate and the scale tracks
the machine's real thermal growth — with an explicit "do not improve it into a one-end anchor later".
That rule works because the substrate overwhelms the band: the 45 × 4 aluminium strip is of order
**12,000 kN** axially against a 15 × 4 printed carrier's **~180 kN**. Aluminium *commands* the steel
band. A printed strip commands nothing, and if it is left floating — located only by the bolt heads —
then the tape's own steel band becomes the stiff member and the assembly reports **steel's
11.7 µm/m/K while the machine moves on aluminium's 23.1**. That is precisely the failure the
full-length bond exists to prevent, arrived at from a different direction, and **segmenting makes it
worse rather than better**.

Bonded continuously to the aluminium, the stiffness order is restored and the carrier is a slave.
Unbonded, this design is wrong no matter how the sections are joined.

**⚠️ Open, and both are decisions rather than measurements:**

- **Carrier width.** 40 and 45 have both been said. The block gap is `BLOCK_ROW_GAP` = 45 *measured*,
  so 45 fills it exactly with nothing to spare; 40 leaves 2.5 a side. Four sections at either width
  fit the bed in one run, so the bed does not decide it.
- **Plastic at all, versus aluminium.** The thermal argument above is survivable when bonded, but it
  leaves a creep-prone member and two adhesive layers under the position reference. **An aluminium
  riser with a milled trench has every advantage and no CTE argument to win** — and then the printed
  sections become the laying jig instead, which is a job plastic is unambiguously good at, since
  nothing about a jig's expansion matters once it is off the machine.

**One measurement would sharpen all of this:** the steel band's own thickness, which is recorded
nowhere and decides whether the tape or the carrier is the stiffer member.

#### Mark it on the machine; do not compute it

There is a term that is easy to get wrong and expensive when it is: **where the sensor bore sits on the
150 mm plate.** If the bore is not centred, the sensor's sweep is offset from the plate's sweep, and the
tape's *start position* moves with it. Correct length, placement wrong by 50 mm, and the axis still runs
off the tape at one extreme. So:

1. Jog to one hard stop; mark the extrusion at the sensor bore's centreline.
2. Jog to the other stop; mark again.
3. Cut and lay the tape mark-to-mark plus ~10 mm beyond each.

That is immune to every assumption above - plate width, screw length, where the 76 mm is referenced from
- and it measures the thing that actually matters. It also yields the real travel figures before any
irreversible cut. **Do not take travels from the config:** `$130` read 889 against a real 860 because a
catalog preset overwrote the measured value. That one erred large, the harmless direction here, but it
settles that the configuration is not the authority.

**Sequencing still matters even with the larger margin**, because it does not depend on the number: a
long run is ~800 mm and the spare is ~400, so **no long run can be redone**. The PSA is one-shot, so a
mis-cut or a bad application costs a piece that does not exist. Cut the three long axes first - any
shortfall then lands on Z, which is cheap to re-order and is deferred anyway (§11.9) - and **err long
rather than short**. Overhang costs nothing; a tape stopping short leaves a band at one end of travel
where the axis moves and the counter does not, presenting as lost steps at one extreme and reading like
a mechanical fault.

#### Z's Abbe offset, and why its threshold is looser

The edge mount puts Z's measurement line a lateral distance *d* off the ball-screw axis, so carriage
pitch or roll appears as position error of about *d × θ* - with *d* ≈ 75 mm, 0.001 rad of tilt is ~75 µm,
against a 1.95 µm resolution.

That is acceptable **only because of what §2 scoped**: a DRO and a lost-step alarm, not metrology. The
error is a stable function of position, not noise - the carriage tilts the same way at the same place
every time - and a lost step is a discrete jump that stands clear of a smooth offset.

The consequence: **Z's alarm threshold is set looser than X/Y/A's**, using the per-axis settings §7
already provides. Recorded here so that nobody later tightens Z to match the others and gets nuisance
alarms out of geometry that was chosen deliberately.

#### The sensor mount: a clamped puck in a 35 mm bore

Each endplate and the X gantry plate already has a **35 mm hole**. The mount is a 35 mm aluminium round,
bored at the bottom to clear the RJ45 jack and drilled up the middle for the cable, sliding in that hole
and locked with a band clamp. The custom board (§14) is two-sided: **AS5311 on the tape-facing side**,
jack and passives on the other. Sliding the puck sets the 0.3 mm gap - close with a feeler gauge, then
**confirm with the sensor itself**: `MagINCn` and `MagDECn` are both off only in the GREEN range (§1.3),
which tests the thing that actually matters (field amplitude) rather than a proxy for it. Aluminium is
required here; steel would distort the field.

**Bore: 30 mm deep** (decided 2026-08-25). The board sits hard at the bottom of the puck - the AS5311 has
to be within 0.3 mm of the tape - so the whole 30 mm is above the board's top face, and it is spent like
this:

| | |
|---|---|
| Jack above the PCB (`69255` DIM C) | 15.62 mm |
| **Left for the plug tail + boot** | **14.38 mm** |

**That makes the slim patch cable a requirement, not a preference.** A standard RJ45 boot stands roughly
20 mm proud of the jack opening and **will not fit** - the plug would bottom out against the end of the
bore before it latched, or hold the puck off its setting. The slim cables (§14, *Choosing the actual
cable*) are far shorter and are what this budget assumes.

Two things to check against a real cable before machining: that the plug **latches** with 14.38 mm of
clearance, and that it can be **released** in situ - a latch tab needs finger or tool access, and a
recessed one 15 mm down a 35 mm bore may not have it. If it does not, that is an argument for the
13.62 mm variant of the jack, which buys back 2 mm.

Open, and worth settling before machining:

- **Anti-rotation.** A round puck in a round hole can spin, and the Hall array is a 2 mm *line* that must
  stay parallel to travel; a band clamp resists rotation only by friction, which vibration erodes. Two
  independent fixes, both worth doing: put the **die centreline on the puck's axis** so rotation cannot
  translate the array (note this means the chip is *not* centred on the puck, since the die sits ~3 mm
  along the package), and add a **positive feature** - a milled flat with a set screw, or a dowel.
- **Repeatable depth.** Servicing the cable means pulling the puck, which loses a gap that was set by
  clamp friction. A shoulder or stop collar that bottoms against the plate makes the setting a mechanical
  constant rather than something to re-dial each time.
- **The puck does not transfer to Z.** It sets a gap perpendicular to the plate face; Z's tape is on the
  plate *edge*, so the sensor approaches from the side and needs a different bracket - with the slide,
  clamp and feeler-gauge adjustment reinvented in that geometry.
- **Z's plate edge must be machined flat and parallel to the travel.** Gap tolerance is a few tenths and
  field strength falls off with it, so an edge wandering more than ~±0.1 mm walks from green into yellow
  partway along. Milled is fine; sawn or sheared is not. The other three axes mount to already-machined
  surfaces, which is the real reason Z is the awkward one (§11.9).
- **Swarf.** The tape is an exposed magnet and collects ferrous debris, which reads as position noise or
  jams the gap. Wood and aluminium chips are harmless; steel is not. Prefer faces that point down or
  inward, and check whether the tape is available with a stainless cover strip.

## 2. Scope

Decided 2026-08-21:

| | In scope |
|---|---|
| **Readout (DRO)** | Report actual position beside commanded, in the `?` report, shown in ioSender |
| **Lost-step alarm** | Raise an alarm when the deviation exceeds a settable per-axis threshold |

**Closed-loop correction is explicitly OUT.** grblHAL is an open-loop step generator whose planner has no
concept of a position error to null out. Feeding measurement back into motion is not a plugin, it is a
motion-control redesign, and a wrong sign or a stale frame *drives* an axis rather than reporting it. If
that is ever wanted it should be a separate design, starting from whether grblHAL is the right firmware
for it at all.

That boundary is what keeps this project tractable: **everything below is observational.** The plugin
reads, compares, and reports. The only action it ever takes is raising an alarm.

## 3. The limit switches stay

Asked 2026-08-21 whether the scales could replace the proximity sensors. **No.** The reasoning, because
this is exactly the kind of decision that gets re-litigated later.

### What a reader does at the end of a tape

The A/B pair carries **no validity information**. As the reader runs past the end of the tape the field
weakens and one of two things happens: the outputs freeze at their last state, or they chatter as the
sensor crosses its detection threshold and emit phantom counts in an arbitrary direction.

Neither is distinguishable, at the ESP32, from a genuinely stationary axis. **The failure is silent**,
and that alone settles it.

> **Refined 2026-08-25, and only partly.** The *A/B pair* still carries no validity information — that
> stays true. But the AS5311 has a separate `MagDECn` pin that is asserted exactly when the field is out
> of range, which is what an off-tape reader sees (§1.3). So the condition **is** detectable if that pin
> is wired, and the plan is to wire it. The conclusion below does not change: the reasons in
> *Fail-closed versus fail-open* and *Three more reasons* are each sufficient on their own and none of
> them depends on detectability.

### Fail-closed versus fail-open

| | Limit switch (NC) | Quadrature encoder |
|---|---|---|
| Broken wire | Reads **triggered** - machine stops | Reads **not moving** - machine drives on |
| Dead sensor | Reads triggered | Reads not moving |
| Connector out | Reads triggered | Reads not moving |

A normally-closed switch is fail-closed: every way it can break is a way it stops the machine. The
encoder is fail-open - every way it breaks looks like "all is well, the axis is parked". That is the
wrong direction to fail in for the one device whose job is preventing a crash.

> **The sensors actually fitted are NO, recorded 2026-09-10.** They are **SN04-N** - NPN, normally
> open - so the left-hand column of that table does not describe this machine. A broken wire, a dead
> sensor or a pulled connector all read *clear*, and the machine drives on.
>
> **This does not change the conclusion of §3.** The switches still stay: the three reasons below
> are each independently sufficient, and none of them is about fail direction. What it changes is
> that the fail-closed argument above is currently an argument for a part that is not installed. The
> drop-in NC variant is **SN04-N2** - same body, bracket, cable and wire colours.
>
> Consequences for the wiring are in [`../wiring/breakout-box.md`](../wiring/breakout-box.md); the
> connector that inherited this property, and then lost it, is in
> [`../wiring/db37-axis-interconnect.md`](../wiring/db37-axis-interconnect.md).

### Three more reasons, each independently sufficient

- **Latency.** A hard limit is wired into the driver and can stop motion inside the ISR. A CAN report
  must be decoded, transmitted, received and compared. At a 16k rapid (267 mm/s) the axis is tens of
  millimetres further on before anything can notice that position stopped changing.
- **The encoder is not on the failure path.** A slipped coupling, a pinion that loses a set screw, a
  delaminated tape - in each case the encoder stops representing the axis. The switch is a physical
  backstop that does not care how the axis got there.
- **No absolute position reference.** Homing is seek → back off → re-seek slowly against a physical reference.
  Incremental quadrature has no reference; it counts from wherever it powered up. Without an index track
  on the tape there is nothing to home *to*.

### The specific one that would bite

`Y_AUTO_SQUARE` squares the gantry by homing Y1 and Y2 **independently against their own switches** and
using the difference. That is the entire mechanism, and `$171` is its tuned result. Removing the Y
switches does not cost a convenience, it removes gantry squaring.

`my_machine.h:63` records that squaring was re-enabled once the loose Y pinion set screw was found. That
capability is worth more than two proximity sensors cost.

### What the scales do buy

- **Soft limits that can be trusted.** `$130`–`$132` are dead-reckoned from where homing left them today.
  Measured position makes them real - and soft limits are the layer that stops most crashes before a hard
  limit is ever involved.
- **Continuous rack detection on the gantry.** Two tapes on Y1/Y2 measure squareness all the time, not
  only at homing. Genuinely new: it would have shown the loose pinion as a drift trend rather than as a
  binding symptom.
- **End-of-tape detection - but only if bought for.** See §11.

## 4. Pin allocation - use CAN3 (pins 30 and 31)

The Teensy 4.1 has three CAN controllers: CAN1 (23, 22), CAN2 (0, 1), CAN3 (30, 31).

Checked against `boards/T41U5XBB_map.h` and the active config in `my_machine.h`:

| Bus | Pins | Verdict |
|---|---|---|
| CAN1 | 22, 23 | **Unusable.** 22 = `Z_LIMIT_PIN`, 23 = `M3_LIMIT_PIN` — the Y2 limit that `Y_AUTO_SQUARE` depends on |
| CAN2 | 0, 1 | Free in firmware — neither pin appears anywhere in the board map — but **unverified whether the T41U5XBB carrier breaks them out at all** |
| CAN3 | 30, 31 | **Use this.** 30 = `AUXINPUT1` (ST1), 31 = `AUXOUTPUT0`. Both on accessible terminals |

Why CAN3 rather than chasing CAN2:

- Both pins are already brought out to terminals, so no probing and no hardware question.
- Neither is bound to a function under the current config. `MOTOR_WARNING_ENABLE` is off (would take
  `AUXINPUT1`), `ENCODER_ENABLE` is off (would take it for QEI), and there is no second spindle (would
  take `AUXOUTPUT0` for direction). They are generic `$P` aux ports today.
- **CAN3 is the CAN-FD controller** on the Teensy 4.1; CAN1 and CAN2 are 2.0B only. 64-byte frames mean
  four axes plus sequence and status fit in one frame — which matters for §6.

**Cost:** one aux input and one aux output. `MOTOR_FAULT_ENABLE` uses `AUXINPUT0` (pin 36) and is
unaffected. Removing the two defines from the board map is the whole change on that side.

## 5. The central design problem: staleness

This is the part to get right, and the reason a naive implementation produces a machine that alarms
constantly and gets switched off.

**A measured position is always older than the commanded position it is compared against.** The delay is
the sum of encoder decode, ESP32 processing, CAN transmit, and grblHAL's receive-to-report path. Call it
`T`. During a move, the apparent deviation is:

```
apparent error  =  feed x T   +   real error
```

At a 16,000 mm/min rapid (≈267 mm/s), that first term dwarfs anything a lost step contributes:

| Latency `T` | Apparent error at 267 mm/s |
|---|---|
| 1 ms | 0.27 mm |
| 5 ms | 1.33 mm |
| 10 ms | 2.67 mm |
| 20 ms | 5.33 mm |

A genuine lost step is a fraction of a millimetre. **A threshold loose enough not to trip on latency is
too loose to detect what it exists to detect.** Comparing instantaneous commanded against delayed actual
does not work at any threshold — this is not a tuning problem.

Three ways out, in increasing order of cost:

**(a) Compare only when stationary.** Check at the end of each move, or whenever the planner is idle and
velocity is zero. Latency stops mattering because nothing is changing. Catches the cumulative error that
actually ruins a part, and cannot false-alarm on following distance.
*Recommended for phase 1.* Simple, robust, and it detects the failure that matters — a job that finishes
in the wrong place.

**(b) Compare against a delayed copy of commanded.** Keep a short ring buffer of commanded positions and
compare the measured sample against the commanded value from `T` ago. Needs `T` to be known and stable,
which over CAN it roughly is. Gives continuous monitoring during motion.

**(c) Timestamp both ends and interpolate.** The ESP32 stamps each sample; the Teensy maintains a clock
offset and interpolates commanded position to the sample's timestamp. Most accurate, needs time sync,
and the sync itself becomes a thing that can be silently wrong.

Do (a) first. It is genuinely useful on its own, and it is the baseline against which (b) can be shown
to work — build (b) only when (a) is trusted and its limits are the thing in the way.

## 6. CAN frame design

One CAN-FD frame per sample carrying all four axes, rather than one frame per axis. A single frame is
atomic: every axis comes from the same instant, and there is no partial update to reason about. This
matters most for Y1/Y2, where the whole point is the *difference* between two axes — reading them from
two frames would make rack indistinguishable from sampling skew.

Sketch, not final:

| Field | Bytes | Notes |
|---|---|---|
| `seq` | 1 | Increments per sample; wraps. A gap means a dropped frame |
| `flags` | 1 | Per-source validity, ESP32 reboot indicator, reader fault / weak-field |
| `t_us` | 4 | ESP32 microsecond timestamp — unused by phase 1, present so (b)/(c) do not need a protocol change |
| `pos[4]` | 4 each | Position per axis, signed |

Units: **int32 nanometres** gives ±2.147 m of range at 1 nm resolution — comfortably beyond both machine
travel and any mag tape's real resolution (typically 1–5 µm), with no floating point on the wire and no
scaling convention to get wrong at one end. Note this is the *wire* format; §1.1 is about the ESP32's
internal counter, which is a separate range problem.

Rate: 100 Hz is ample for a DRO and for §5(a). 1 kHz is affordable on CAN-FD if (b) later wants it. Pick
the rate the alarm needs, not the maximum the bus allows — every frame is work on both ends.

`seq` and `flags` are not optional garnish. §8 and §9 depend on both.

## 7. grblHAL integration

Confirmed present in this tree, so none of this requires forking the core:

- **`src/plugins/`** already holds 15 plugins — a supported extension point.
- **`grbl/core_handlers.h:109`** — `on_realtime_report_ptr`, the hook that appends fields to the `?`
  status report. The plugin chains onto it and adds an actual-position field.
- **`grbl/core_handlers.h:104`** — `on_report_options_ptr`, so the plugin announces itself in `$I`.
  ioSender should key its display off that rather than assuming the field exists.

What is genuinely new: **there is no CAN support of any kind in this driver.** Grepped for `FlexCAN`,
`CAN_ENABLE`, `CAN_TX`/`CAN_RX` across the whole tree — zero hits. FlexCAN_T4 integration is from
scratch, and it is the piece with no prior art here to copy.

Note `src/encoder/` and `ENCODER_ENABLE` exist but are **not** reusable: that is spindle/MPG quadrature,
not per-axis linear scales, and it hangs off different plumbing.

### Settings

Plugin settings group, `$`-numbered in the plugin range:

- enable mask (which axes are monitored — partial fitment must be normal, not a special case)
- deviation threshold, per axis
- comms timeout before the feed is declared stale
- what a sustained comms loss does (see §9)

Per-axis threshold rather than one global: a gantry axis has different real-world slop from a ballscrew
Z, and one number forces the loosest axis to set the sensitivity for all of them.

## 8. Reference frame, zeroing, and the reboot problem

The scale measures **its own position along the tape**. grblHAL's machine coordinates come from homing.
These are different origins and nothing correlates them automatically.

- Establish an offset at homing: after a successful home, record `encoder_raw - machine_position` per
  axis. Comparison uses that offset thereafter.
- **The offset is invalid until homing has run.** Before that, report actual position if you like but do
  not compare, and do not alarm. A comparison against an unestablished reference is exactly the kind of
  confident wrong answer that costs a part.
- **If the ESP32 reboots, its count restarts and the offset is silently wrong.** This must be detectable
  — hence the reboot indicator in `flags` and the `seq` discontinuity. On detection: invalidate the
  offset, stop comparing, and say so. Do **not** re-derive the offset automatically from current
  position, because that would define whatever error exists at that moment as zero and permanently
  conceal it.

## 9. Failure modes and what each should do

| Failure | Behaviour |
|---|---|
| No frames since boot | Report "not present". Not an error — partial fitment is legitimate |
| Frames stop mid-job | **Decide deliberately.** See below |
| `seq` gap (dropped frame) | Skip that comparison; count it. A rate worth reporting, not an alarm |
| ESP32 reboot flag | Invalidate offset, stop comparing, require re-home. Never silently re-zero |
| Deviation over threshold | Alarm |
| Reader fault / weak field | Treat that axis as unmonitored, report it. This is the end-of-tape case from §3 — **only available if the reader has such an output** |

The mid-job comms loss deserves thought rather than a default. Alarming on a single glitch is expensive —
it stops a job that was running correctly. Ignoring it silently is worse, because monitoring the operator
believes is running has quietly stopped. Suggested: a visible status flag immediately, alarm only on
**sustained** loss past the configured timeout, with the timeout settable and the flag always visible in
the report so "is it actually watching?" is answerable at a glance.

Whatever is chosen, it must **fail visibly**. The failure mode to design against is not a false alarm —
it is the operator believing an axis is monitored when it is not.

## 10. ioSender side

Both ends are ours, which removes the usual protocol-negotiation problem.

- Parse the new report field; gate on the `$I` option string so an un-flashed controller degrades to the
  existing display rather than showing blanks.
- Show actual beside commanded, and the deviation.
- Y1 vs Y2 difference deserves its own readout, not just two numbers to subtract by eye. That difference
  is the rack, and it is the number with diagnostic value.
- Make "monitoring is live" visibly distinct from "deviation is zero". They look identical on a DRO and
  mean opposite things — a dead feed reads as perfect tracking. This is the same failure the ioSender
  work has hit repeatedly: unknown rendered as a confident value.

## 11. Open questions

Listed so they are not rediscovered. The first two gate a purchase.

1. ~~Does the reader have a signal-valid / weak-field / error output?~~ **Answered 2026-08-25: yes.**
   The AS5311's `MagDECn` pin is asserted exactly in the RED range, which is what an off-tape reader
   (no field) looks like. Wire one per axis into `flags`; decode table and pin budget in §1.3 and §14.
2. ~~Does the tape have a reference/index track?~~ **Answered 2026-08-25: effectively no.** The AS5311
   emits an Index pulse, but once per 2 mm pole pair — it repeats, so it is not a unique position and homing-to-index
   is not available from it (§1.3). The scales stay purely relative; §8 stands unchanged.
3. ~~Tape resolution and repeatability~~ **Answered 2026-08-25 from the datasheet** (§1.3): 1.95 µm/step
   incremental, 3.9 µm hysteresis, 0.6 µm RMS transition noise, ±0.97 µm DNL. So §5's threshold cannot
   usefully go below ~5 µm. Still worth **measuring on the actual machine** — the quoted figures assume an
   ideal magnet at the specified 0.3 mm gap, and the mounting will not be ideal.
4. **Measured end-to-end latency `T`.** §5 is parameterised on it. Measure, do not estimate.
5. **Bus topology and termination** — node count, cable length, whether anything else ever joins.
6. ~~What do the Hall readers output?~~ **Answered 2026-08-21: A/B quadrature**, into ESP32-S3 PCNT.
7. ~~Which axes get tapes?~~ **Answered: four — X, Y1, Y2, Z.**
8. Whether the ESP32 is needed at all, or whether the readers could feed the Teensy directly. Cable
   length and noise argue for the ESP32 at the machine end; pin scarcity on the Teensy argues the same
   way. Recorded as considered and rejected for those reasons, not overlooked.
9. **How the Z reader mounts.** The other three are placed (§1.4); Z is the awkward one - the sensor has
   to come out of the side of the Z plate, and the scale has to go somewhere that survives the full Z
   travel. Still in scope, still unsolved mechanically. Its GPIOs and PCNT unit stay reserved (§14) so
   nothing has to be rearranged when it is.
10. **Whether the spindle cable stays in the drag chain** (§14). Running as-is for now; the fallback route
    is already chosen. Listed because the answer arrives as drifting counts, not as an obvious fault.

## 12. Phasing

Each phase is independently testable and useful on its own — the point being that nothing later is a
prerequisite for value from what is already done.

1. **ESP32-S3 → CAN, standalone.** Frames on the wire, verified with a bus analyser. No Teensy
   involvement. Includes PCNT overflow accumulation (§1.1) — prove a count survives many wraps before
   trusting anything downstream of it.
2. **FlexCAN_T4 receive on the Teensy.** Frames arriving, counted, logged. No grblHAL integration.
3. **Plugin + `on_realtime_report`.** Actual position in the `?` report. Read-only, no comparison.
4. **ioSender display.** The chain is now visible end to end, which is what makes phase 5 debuggable.
5. **Offset at homing + stationary comparison + alarm** (§5a). The first phase that can stop a machine —
   and worth its own hardware-verified session rather than being tacked onto phase 4.
6. Optional: continuous monitoring during motion (§5b), once (a) is trusted.

## 13. Evidence already gathered

So the next session does not repeat it:

- `boards/T41U5XBB_map.h` is the pin map; `my_machine.h:60` selects the board; `driver.h:~103` chains
  them. `boards/generic_map.h` is included **after** as a fallback, so a mistyped pin name silently takes
  a default instead of failing to compile — grep the exact symbol when overriding.
- Pins 22, 23 taken (Z limit, M3/Y2 limit). Pins 0, 1 unreferenced in this board map. Pins 30, 31 are
  `AUXINPUT1` / `AUXOUTPUT0`, unbound under the current config.
- Active config: `Y_GANGED` + `Y_AUTO_SQUARE` (so `N_ABC_MOTORS` = 1, M3 in use, M4 not),
  `MOTOR_FAULT_ENABLE` on `AUXINPUT0` (pin 36), `TOOLSETTER_ENABLE` on `AUXINPUT6` (pin 29),
  `CONTROL_ENABLE 0`, no `ENCODER_ENABLE`, no `MOTOR_WARNING_ENABLE`, no second spindle.
- No CAN support anywhere in the driver tree.
- ESP32-S3 PCNT: 4 units, 2 channels each, 16-bit signed counters.

## 14. Encoder wiring - AS5311 to ESP32-S3

Longest run **2.4 m** (user, 2026-08-25). Sensor specs in §1.3; header pin map in
[`hardware-esp32-s3-rs485-can.md`](hardware-esp32-s3-rs485-can.md).

### Bandwidth is a non-issue; noise is the whole problem

512 steps/mm means **128 quadrature cycles/mm**, so even a 5 m/min rapid is only **~10.7 kHz per
channel** - a 93 µs period against a cable that settles in well under a microsecond. Length,
capacitance, reflections and propagation simply do not matter at 2.4 m.

What matters is that **quadrature has no error recovery**. One induced glitch is one count, permanently.
It never self-corrects, the position stays wrong until the next homing, and it reads as an entirely
plausible number. That is the same silent-wrongness this whole document is organised around (§3, §5,
§9), arriving through the cable instead of through the sensor.

The enormous timing margin is the thing to spend: filter aggressively, because nothing here is fast.

### The build

1. **Run the AS5311 at 3.3 V, not 5 V.** The datasheet supports either, and V<sub>OH</sub> = VDD-0.5
   gives a 2.8 V high - comfortably above the S3's V<sub>IH</sub>. **ESP32-S3 GPIOs are not 5 V
   tolerant**, so the 5 V option means level-shifting every line. There is no reason to take it.
2. **Shielded cable, twisted pairs, each signal twisted with its own ground return** - A/GND, B/GND,
   and a pair for 3V3/GND. *Not* A twisted with B. Pairing a signal with its return is what shrinks the
   loop area, and loop area is what couples the noise. 24 AWG multi-pair instrumentation cable, or
   CAT5e F/UTP, is fine.
3. **Shield to chassis at the ESP32 end only.** Both ends is a ground loop that injects current into the
   signal return.
4. **Series 100-220 Ω at the AS5311 output, 330 pF-1 nF to ground at the ESP32.** An RC in the tens of
   nanoseconds is invisible to a 10 kHz signal and swallows coupled spikes.
5. **Decouple at the sensor** - 100 nF + 10 µF. 2.4 m of 24 AWG has enough R and L that a supply dip
   during stepper commutation appears as an output glitch.
6. **Enable PCNT's hardware glitch filter.** Free rejection of anything under a microsecond, in the
   counter itself. Confirm the ESP32-S3 driver's API and units when implementing.
7. **Route away from motor phase and VFD cable** - separate bundle, separate drag-chain lane where
   possible, cross at 90°.

### The spindle cable shares the drag chain - the one to watch

Per §1.4 the two gantry-end cables run inside the extrusion and then through the drag chain, which today
also carries **the spindle cable** and the stepper cables. A VFD spindle lead is the worst emitter on the
machine - fast PWM edges into a long cable - and in the chain it runs *parallel* to the encoder cables
for their whole length, which is the geometry that couples best.

Two things soften it: these signals are slow enough to filter hard, and the gantry portion is inside
aluminium extrusion. The steppers matter much less - slower edges into a non-switching load.

**The decision, so it is not re-derived while debugging:** run it as-is, but if anything looks wrong, the
spindle cable is the **first** thing to move, not the last. The route is already identified - overhead
with the coolant and air lines, out of the chain entirely. What makes this worth writing down is the
failure signature: not "it does not work", but counts drifting over hours, which reads exactly like lost
steps and sends you looking at the mechanics.

Regardless of chain sharing: the spindle cable must be shielded with **its shield landed at the VFD
end**, and the encoder cables should use a different channel of the extrusion from anything switching.

**If count drift ever appears**, escalate to RS422: AM26C31 driver at the sensor, AM26C32 receiver at
the ESP32. That is what industrial encoders do and it makes 2.4 m trivially safe. Held in reserve rather
than built first, because these signals are slow enough that the measures above should be sufficient -
and the escalation is two ICs and a 2-pair cable per axis whenever it is needed.

### Pin budget - it fits exactly

12 free GPIOs on the header (IO3-IO14):

| Signal | Count | Pins |
|---|---|---|
| A/B quadrature, 4 axes | 8 | 4 PCNT units, both channels each |
| `MagDECn`, one per axis | 4 | per-axis RED / off-tape flag (§1.3) |
| **Total** | **12** | exactly IO3-IO14 |

`MagDECn` alone is the useful line: asserted ⟺ RED, so it gives a clean per-axis fault without needing
`MagINCn` too. If the YELLOW early-warning is wanted later, the four `MagINCn` pins are open-drain and
so **wire-OR onto a single line** with one pull-up - and `IO1`/`IO2` are still free on the SH1.0
connector, off the 20-pin header entirely. Use a stiffer pull-up (~2.2 kΩ) and filter it hard: a
high-impedance open-drain bus over 2.4 m is the most noise-prone thing in this design, and it is a
static signal, so there is no cost to filtering it heavily.

### CAT5, one cable per sensor - and the pair count is what decides it

Each sensor needs five conductors' worth of signal - 3V3, GND, A, B, `MagDECn` - and CAT5's four pairs
give exactly four signal-plus-return pairs. It fits, with nothing spare:

| Pair | T568B pins | Colours | Carries |
|---|---|---|---|
| 2 | 1, 2 | white-orange / orange | **A** + GND return |
| 3 | 3, 6 | white-green / green | **B** + GND return |
| 1 | 4, 5 | blue / white-blue | **3V3** + GND (power pair) |
| 4 | 7, 8 | white-brown / brown | **MagDECn** + GND return |

All four GND conductors are the same net at both ends. That is intended: at DC the return splits by
resistance, but the fast edges - the part that couples - return through the adjacent conductor in their
own twist, which is what collapses the loop area.

**Do not trunk several sensors into one cable.** Eight conductors would carry eight signals with *no*
returns, single-ended against a distant ground - strictly worse than unshielded zip cord. The pair
count, not tidiness, settles the earlier open question: **one cable per sensor.**

Power over one pair is ample. The AS5311 draws 16 mA typ / 21 mA max (§1.3), so 2.4 m of 24 AWG drops
~8.5 mV round trip, and even 28 AWG slim cable only ~22 mV, against a 3.0 V minimum on a 3.3 V rail.

`Index` gets no conductor: per §1.3 it is not a unique position.

### Choosing the actual cable

- **Shielded (F/UTP or S/FTP).** Not optional here - it is the whole §14 premise. Many slim patch cables
  are UTP; check before buying.
- **Stranded, and continuous-flex rated for the drag-chain run.** Structured-wiring CAT5 is solid core
  and **will work-harden and break** in a drag chain. Patch cable is stranded and better, but still not
  built for continuous flexing; the run through the chain wants proper flex/torsion-rated Ethernet cable.
  The static runs inside the extrusion can be anything.
- **28 AWG slim is electrically fine** (see the drop above) and the small bend radius suits a drag chain.
- **"It works fine for PoE" does not transfer.** Ethernet is differential, transformer-isolated, and
  error-corrected; PoE only proves current capacity. These are single-ended CMOS signals with no error
  detection, where one coupled glitch is a permanent count error. The cable can be excellent for one and
  marginal for the other.

### Connectors - let the jack enforce the single-point shield ground

§14 requires the shield bonded at the controller end **only**. Shielded RJ45 hardware defeats that by
default: metal-shell plugs bond shield to jack shell at both ends, creating exactly the ground loop
being avoided. Choose the hardware so it cannot happen:

- **Controller end: shielded (metal) PCB jack**, shell bonded to chassis. This is the intended ground.
- **Sensor end: plastic, unshielded jack.** The plug's shield shell then has nothing to bond to, so the
  foil/drain floats at that end - correct by construction rather than by remembering.
  **Part chosen: Amphenol ICC `69255-004LF`** - 8P8C, vertical, through-hole, unshielded, **no integrated
  magnetics**. Its Cat3 rating is irrelevant here: that is an Ethernet bandwidth grade, and these are
  DC-coupled signals at ~10 kHz. Drawing in [`manufacturer-assets/`](../manufacturer-assets/index.html).
  **Height above PCB (drawing DIM C): 15.62 mm** - 13.62 mm on one variant of the series, worth
  identifying before ordering if the puck's bore depth gets tight (§1.4). "Vertical" means the plug
  inserts perpendicular to the board, i.e. along the puck axis, which is what suits the cable running
  straight up the middle.

**Buy jacks WITHOUT integrated magnetics - both ends.** A large fraction of PCB RJ45 jacks are MagJacks
with transformers inside. They pass Ethernet perfectly and **block DC completely**, and every signal
here is DC-coupled, so a MagJack means nothing works at all. Check the part number on the 4-jack
controller board as well as on the sensor boards.

### The sensor board: carry the chip, not a breakout

Decided 2026-08-25: **a custom board with the AS5311 on it**, an RJ45 jack and the passives - not a
carrier that a breakout plugs into. The reason is mechanical, not electrical.

What decides accuracy is where the **Hall array** sits relative to the magnetic strip, and Figure 14
(p.21 of [`AS5311-Datasheet.pdf`](../manufacturer-assets/index.html)) gives the reference dimensions: the array is **2.0 mm long,
centred on the die centreline**, which sits **3.035 ±0.235 mm** along the package and **2.576 / 3.200
±0.235 mm** across it, with **0.245 ±0.100** and **0.755 ±0.100 mm** around the die plane vertically.

**Those tolerances are the point.** The die's position inside its own package is already ±0.235 mm,
against a ±0.5 mm lateral budget (§1.3). There is no room to stack a breakout's mounting-hole tolerance
and an adapter on top of it. On a custom board the array-to-mounting-hole relationship is a fab
tolerance (~±0.1 mm) that is *yours*, and dropping the stacked board and headers also gets the package
closer to the strip - the other half of the same budget. TSSOP-20 on 0.65 mm pitch is hand-solderable,
so the chip is not the obstacle.

Transfer those reference dimensions from the figure directly when laying out; the numbers above were read off a
rendered page and the reference edges deserve a second look.

#### The pins a breakout was quietly handling

| Pin | Must be | Why it matters |
|---|---|---|
| **14 CSn** | **tied LOW** | "Must be low to enable incremental outputs", and it has an internal ~50 kΩ pull-up. Left floating, **A/B/Index stay locked high after power-up** - the board looks and measures dead. |
| **9 Prog** | to VSS | OTP programming input |
| **18 VDD3V3** | to VDD5V | Regulator output, "do not load externally" - it is not a second rail. This is how 3.3 V operation is selected. |
| **1, 6, 10, 11, 16, 17, 20** | **left unconnected** | The datasheet says so for each. Do not ground NC pins out of habit. |
| **2 MagINCn / 3 MagDECn** | open-drain | Need a pull-up: put it at the **controller** end (~2.2 kΩ) with the RC, so the long line is held stiffly where it is read. |

Tie CSn low through a **0 Ω or solder jumper** rather than a hard trace. Lifting it later allows SSI
readout - absolute position within the pole pair plus the full status word (OCF, COF, LIN, parity),
a far better bench diagnostic than the two hardware pins. Bring CLK and DO to test pads: no GPIO cost.

Also on the board: the series resistors at the source and the 100 nF + 10 µF decoupling (both have to be
at this end anyway), a TVS array on the connector side because it gets handled, and the plastic
unshielded jack per the shield rule above. **Panelise four** - three now, Z later (§11.9).

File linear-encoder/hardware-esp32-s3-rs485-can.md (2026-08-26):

# Waveshare ESP32-S3-RS485-CAN - pin allocation

The module in [`design-can-position-feedback.md`](design-can-position-feedback.md): an ESP32-S3 that
decodes the Hall readers' A/B quadrature in PCNT and reports position to the Teensy over CAN.

**Why this file exists:** the Waveshare wiki does **not** document the 20-pin header's GPIOs - it lists
only the 4-pin SH1.0 connector. The header map exists solely in the schematic, as component `P1`, so it
is easy to look for and conclude it was never published. It was extracted here once and lost; the
schematic is kept in `manufacturer-assets/` (untracked; its `index.html` says where it came from).

## Sources

| What | Where |
|---|---|
| Wiki | <https://www.waveshare.com/wiki/ESP32-S3-RS485-CAN> |
| Schematic (the authority for everything below) | `ESP32-S3-RS485-CAN-Schematic.pdf` in [`manufacturer-assets/`](../manufacturer-assets/index.html) - untracked; source <https://files.waveshare.com/wiki/ESP32-S3-RS485-CAN/ESP32-S3-RS485-CAN-Schematic.pdf> |

Both waveshare.com URLs return **HTTP 403 to a plain fetch**; they serve normally with a browser
User-Agent. That is what makes this hard to re-find with a tool rather than a browser.

## P1 - the 20-pin header (2x10, 2.0 mm pitch)

Odd pins are the left column, even the right.

| Pin | Signal | | Pin | Signal |
|---|---|---|---|---|
| 1 | 3V3 | | 2 | 5V |
| 3 | GND | | 4 | GND |
| 5 | TXD - GPIO43 (U0TXD) | | 6 | D_P - GPIO20 (USB D+) |
| 7 | RXD - GPIO44 (U0RXD) | | 8 | D_N - GPIO19 (USB D-) |
| 9 | **IO3** | | 10 | **IO14** |
| 11 | **IO4** | | 12 | **IO13** |
| 13 | **IO5** | | 14 | **IO12** |
| 15 | **IO6** | | 16 | **IO11** |
| 17 | **IO7** | | 18 | **IO10** |
| 19 | **IO8** | | 20 | **IO9** |

**Twelve free GPIOs on the header: IO3-IO14.**

`TXD`/`RXD` are labelled by function, not number, in the schematic. They are GPIO43/GPIO44: they land on
module pins 49/50 (`U0TXD`/`U0RXD`) and sit between `IO42` and `IO45` in the schematic's own numerically
ordered GPIO table. Identified from the document, not assumed.

## What the board already uses

From the GPIO allocation table on the left of the schematic.

| Function | GPIOs |
|---|---|
| CAN / TWAI | **IO15 = TXD2, IO16 = RXD2** |
| RS485 | **IO17 = TXD1, IO18 = RXD1, IO21 = RS485_EN** (automatic direction switching) |
| USB | IO19 = D_N, IO20 = D_P |
| RTC (PCF85063) | IO38 = SCL, IO39 = SDA, IO40 = INT |
| Internal (PSRAM / flash) | IO33-IO37 |
| Boot button | IO0 |
| UART0 | GPIO43 (TXD) / GPIO44 (RXD) - also on header pins 5 and 7 |

That table's **Relay, DIN, Network, EXIO and SD Card columns are empty** on this board - it is a table
shared across the product family, so a blank column means "not fitted here", not "undocumented".

**IO1 and IO2 are not on P1.** They come out on the SH1.0 connector `J4` (GND, 3V3, GPIO2, GPIO1) - the
only GPIOs the wiki page itself documents.

## Consequences for the encoder design

Four axes x A/B = **8 inputs**, and IO3-IO14 gives 12. Comfortable, and it matches
[`design-can-position-feedback.md`](design-can-position-feedback.md) §1.1: PCNT has exactly 4 units,
one per axis, no spare.

- **GPIO3 is a strapping pin** (JTAG source select) on the ESP32-S3 - fine as an input after boot, but
  it must not be driven during reset. This is general ESP32-S3 knowledge, **not** from this schematic.
  Using IO4-IO14 and leaving header pin 9 unused sidesteps the question entirely.
- **IO19/IO20 are USB.** They are on the header as D_N/D_P; taking them costs the USB port.
- Nothing else on the header is shared with the RS485 or CAN transceivers, so an encoder harness on
  IO4-IO14 cannot interfere with the bus this board exists to drive.

## Board power

DC 7-36 V wide-input screw terminal, 3.3 V / 2 A onboard DC-DC, plus USB Type-C (power, flashing,
communication). Isolated RS485 and CAN sides, each with a jumper-enabled 120R termination resistor.

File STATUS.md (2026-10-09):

<!-- GENERATED by tools/status.py - DO NOT EDIT -->
# Open items

**Generated.** Edit the prose, then run `tools/status.py status`.

Every open decision across the repo, harvested from the markers in the prose. The
`machine/*.md` files remain authoritative: this page is a view of them, not a second
copy, and it **cannot go stale** because it is rebuilt rather than maintained.

That property is the whole point. On 2026-10-02 two settled decisions were relitigated
because a **hand-written** open-items list had drifted from the text it summarised — one
entry claimed the three-point mount was undocumented while `torsion-box.md` described it
in full, and another carried a dimension the body text had already corrected.

⚠️ **Classification is a heuristic:** an item is open if it carries ⚠️ or 🔴 and is not
also marked ✅. When that reads wrong, **fix the markers in the prose** — they are the
interface, not this file.

## [machine/assembly.md](machine/assembly.md)  (63)

- ⚠️ [L15](machine/assembly.md#building-the-machine) — *Building the machine*<br>Items marked Open are not yet specified anywhere in this repo. They are not omissions from this document — do not fill one in from a catalogue or from inference. open-items.md is the full list.
- 🔴 [L52](machine/assembly.md#order-of-work) — *Building the machine / Order of work*<br>The machine is assembled on a flat surface and its width measured off the standing assembly. That measurement is what the box skins are cut to — so the machine comes before the box, not after it.
- 🔴 [L55](machine/assembly.md#order-of-work) — *Building the machine / Order of work*<br>The spindle and tram come last, after the machine is bolted to the box. Tram is set in the installed position or it is set against a reference the machine does not have yet.
- 🔴 [L97](machine/assembly.md#1-the-mill-trip) — *Building the machine / 1. The mill trip*<br>Five plates stand on the box and all five are 301.625 high: the two side plates, the back plate and the two front fins. Measure all five against each other as they arrive, before any of them is drilled. A part that is not 301.625 is misordered or mismade — send it back. Two parts wrong by the same amount would still assemble, so check them against each other and not only against the number.
- ⚠️ [L120](machine/assembly.md#1-the-mill-trip) — *Building the machine / 1. The mill trip*<br>Open: whether the mill can hold one height reference across the 1210.73 mm rear plate. Bed size is not travel. The two 8-bolt patterns' relative height must land well inside 1 mm across the metre. If the part is repositioned mid-job, indicate the first pattern back in before drilling the second, and work from a scribed and indicated line rather than from a sawn edge.
- 🔴 [L133](machine/assembly.md#load-every-t-nut-first) — *2. The beams / Load every T-nut first*<br>The 13025 T-nut slides in from the end of the slot. Once a joining plate or an end plate closes the slot ends, the only way to add one is to take the beam apart.
- ⚠️ [L144](machine/assembly.md#load-every-t-nut-first) — *2. The beams / Load every T-nut first*<br>The front strip's two slots are the ones that get forgotten while counting out the back, and they are just as closed once the ends are on. Count them twice.
- 🔴 [L163](machine/assembly.md#mount-the-rails) — *2. The beams / Mount the rails*<br>Bias every bolt the same direction as you tighten it, and bias both rails the same way. The hole is a clearance hole and the T-slot adds more float; tighten 17 bolts with the rail floating and it snakes. Common mode — both rails pulled the same way. Do not pull the two rails apart or together.
- 🔴 [L185](machine/assembly.md#join-the-stack) — *2. The beams / Join the stack*<br>The lengths are not interchangeable, and the long one fails silently. There is 1.2 mm of air behind the T-nut (slot floor measured at 9.5, nut back face at 8.3), so a bolt may reach at most 7.2 mm past the back of a plate. An M8 × 12 in the 4 mm front strip reaches 8.0 and bottoms on the slot floor before its head seats - it feels tight and the strip is still loose. Engagement is capped at 6 mm by the nut, so a longer bolt buys nothing anywhere on this machine. The washer on the Y back is margin, not decoration: bare, that bolt clears by 0.24 mm if the sheet is the 11-gauge it was sourced as. Full derivation in gantry-beam-joint.md.
- 🔴 [L197](machine/assembly.md#join-the-stack) — *2. The beams / Join the stack*<br>The front strip is 4 mm, not 1/4". At 1/4" the flange head rim passes under the bearing block and hits — there is at most 6 mm of clearance there, and the 1/4" stack is 7.35.
- 🔴 [L200](machine/assembly.md#join-the-stack) — *2. The beams / Join the stack*<br>The front strip's 14 flange bolts must be austenitic stainless — A4 / 316. The magnetic encoder tape runs on this strip's face, and ferromagnetic bolt heads 1 mm from a magnetic scale put a periodic error at the bolt spacing into the axis. 42 bolts across the three beams.
- ⚠️ [L204](machine/assembly.md#join-the-stack) — *2. The beams / Join the stack*<br>Put a magnet on them when they arrive. Generic "stainless" bolts bought for this job were tested and are magnetic. 410, 416 and 430 are sold as stainless and are as bad as carbon steel here. Ask for A4 rather than A2. Socket heads are fine if A4 flange heads are awkward to source — a 13 mm socket head leaves more room for the tape than the flange does.
- 🔴 [L223](machine/assembly.md#the-magnetic-tape) — *2. The beams / The magnetic tape*<br>The clear lane is sized by the SENSOR, not by the tape. The AS5311 puck needs 15 mm kept clear centred over the tape - the PCB and its mounting points, not the chip - which leaves 0.6 mm each side. At the old 17.3 mm head the lane was 12.7 and the puck did not fit at all, which is why the bolt changed. The bolt rows cannot move to help: they are at ±15 because that is where the extrusion's T-slots are.
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

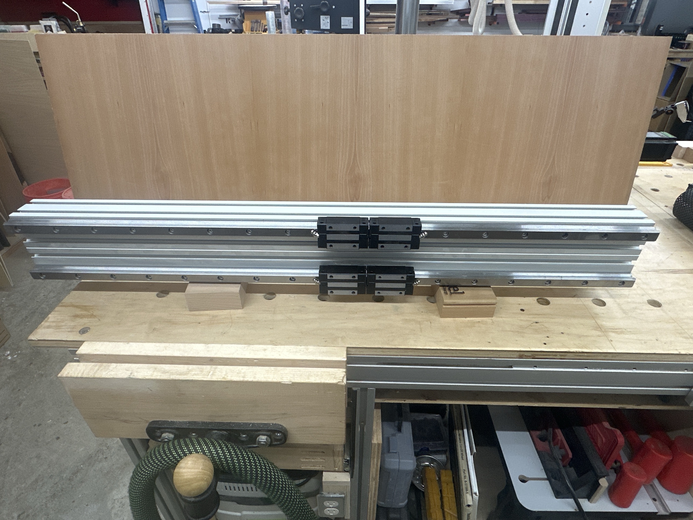
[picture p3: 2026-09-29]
machine/photos/gantry-stack-rails-front.jpg

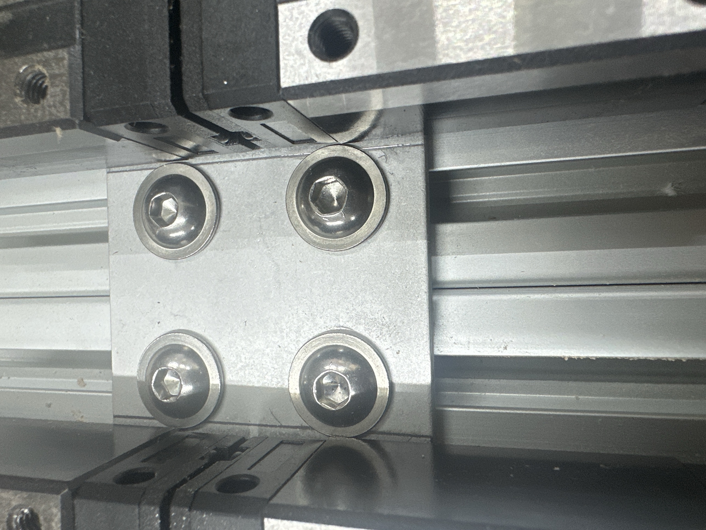
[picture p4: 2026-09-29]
machine/photos/front-plate-trial-flange-bolts.jpg

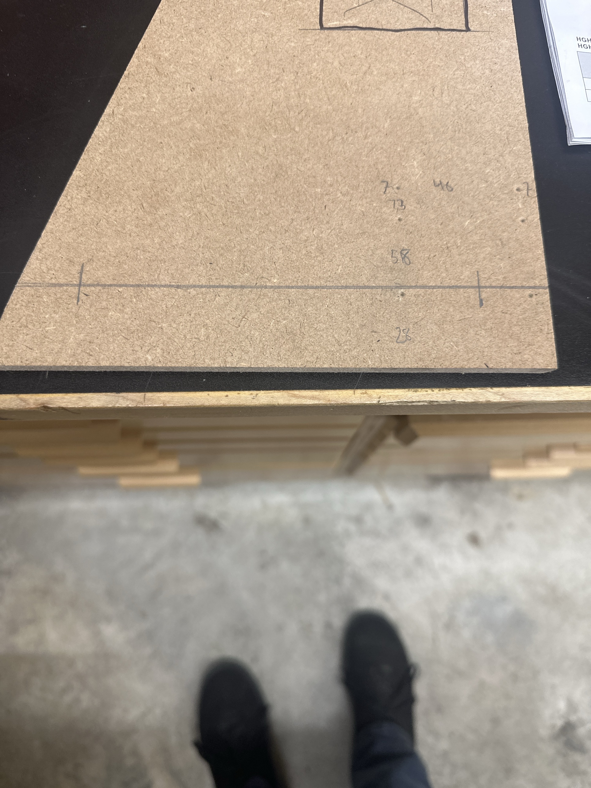
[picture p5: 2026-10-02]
machine/photos/front-fin-template-tongue-bolts.jpg

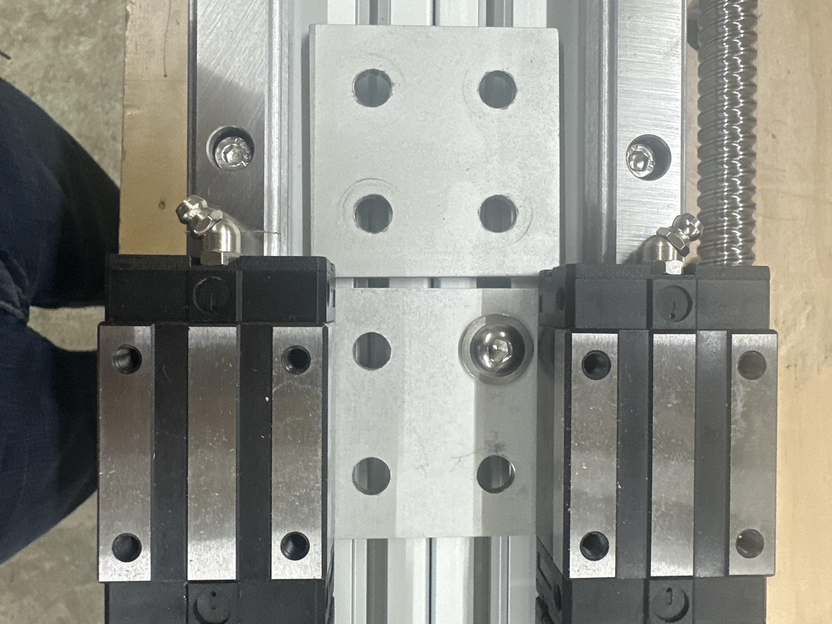
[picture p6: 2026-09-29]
machine/photos/front-plate-trial-single-bolt.jpg

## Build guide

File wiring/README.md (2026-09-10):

# Wiring

How the boxes connect to each other and to the machine. Decisions, not measurements - anything
metered off the machine belongs in [`../commissioning/`](../commissioning/).

| | |
|---|---|
| [`db37-axis-interconnect.md`](db37-axis-interconnect.md) | Controller box ↔ remote breakout box: one 1.5 m DB37 carrying Step/Dir/EN/GND/AL/Limit for five axis blocks, plus the 5 V and 12 V pairs beside it |
| [`breakout-box.md`](breakout-box.md) | What is in the breakout box, the Mini-Fit Jr back panel, the SN04-N limit sensors, and the one ground arrangement that matters |

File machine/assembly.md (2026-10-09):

# Building the machine

**How the machine goes together.** Parts, hardware, and what bolts to what, in the order it is
done.

This document states the build and nothing else. It does not carry the reasoning, the options that
were weighed, or what any figure used to be — that is the design record, the thirteen chapters listed
in [`README.md`](README.md), and it is a separate printout. **Where this document and a chapter
disagree, the chapter wins.**

**Drilled hole coordinates are not here.** They are on the sheets in
[`drawings/shop-pack.html`](drawings/shop-pack.html), one sheet per part. This document says which
parts meet, with what hardware, and when.

⚠️ **Items marked Open are not yet specified anywhere in this repo.** They are not omissions from
this document — do not fill one in from a catalogue or from inference. [`open-items.md`](open-items.md)
is the full list.

---

## The machine

| | |
|---|---|
| Beams, all three axes | **Two 8020 `30-6060` stacked** — 60 mm wide × 120 mm tall, **1000 mm** long |
| Axes | X, a ganged **Y1 / Y2** pair, and Z. `Y_GANGED` + `Y_AUTO_SQUARE` in firmware, so the second Y motor is M3 |
| Rails | **HGR20**, one per profile, in the **outside** T-slot — rails 90 mm apart on each beam. **Y rails face each other**, on the beams' inside faces |
| Ball screws | **1605** on every axis, through a **cast stepper frame** at one end and **BF12** at the other |
| Screw position | **X on top** of its beam; **both Y underneath** theirs |
| Steppers | **2.2 N·m, NEMA 23 — four, one per axis.** **Y steppers at the FRONT** of the machine |
| Y beams | Fixed — their end plates bolt to the torsion box. Only X, Y-carriage and Z move |
| Spindle | **Ø80 mm, 2.2 kW water-cooled**, 5.2 kg, on two 80 mm clamps |
| Stands on | A sand-filled **torsion box** on **three cedar posts**, on a 2x6 base frame that is also the pallet |

### Rails come from two suppliers

| Axes | Kit |
|---|---|
| **X, Y1, Y2** | one HGR20 kit, one supplier |
| **Z** | a **400 mm** HGR20 kit, **a different supplier** |

**A dimension measured on the Z kit is a Z dimension.** Measure the X/Y kit separately for anything
that sets a plate.

---

## Order of work

**The box is cut from the standing machine, and the spindle goes on after the box.** Two ordering
rules carry the whole sequence, and neither can be worked around:

- 🔴 **The machine is assembled on a flat surface and its width measured off the standing
  assembly.** That measurement is what the box skins are cut to — so the machine comes before the
  box, not after it.
- 🔴 **The spindle and tram come last, after the machine is bolted to the box.** Tram is set in the
  installed position or it is set against a reference the machine does not have yet.

| | Stage |
|---|---|
| 1 | [Make the plates](#1-the-mill-trip) — one trip to the mill |
| 2 | [Build the three beams](#2-the-beams) — T-nuts, rails, joining plates |
| 3 | [The Y beam ends](#3-the-y-beam-ends) — interposers, castings, screws, fins, rear plate, outboard plates |
| 4 | [The X gantry](#4-the-x-gantry) — end plates, shelves, beam, carriage plate |
| 5 | [The Y ball nuts](#5-the-y-ball-nuts) — doublers and sole brackets |
| 6 | [The Z axis](#6-the-z-axis) |
| 7 | [Stand it up and measure](#7-stand-it-up-and-measure-it) — this is where the box width comes from |
| 8 | [Build the box and its base](#8-the-torsion-box) |
| 9 | [Set the machine on the box](#9-set-the-machine-on-the-box) |
| 10 | [Fit the spindle and **tram**](#10-fit-the-spindle-and-tram), then the [stiffness test](#then-run-the-stiffness-test) |
| 11 | [Fill the sand](#11-fill-the-sand) |

---

## 1. The mill trip

Accurate holes are drilled on **one visit** — a Laguna mill, 4' × 1' bed, **manual X and Y**.
Every plate must be fully dimensioned before the trip, including assemblies that will not be built
for months.

| On the mill | |
|---|---|
| Two **Y front plates / fins**, 10 mm | the 8-bolt corner-bore pattern and the 60.5 × 50 window |
| The **1210.73 mm rear plate**, 1/4" steel | two 8-bolt patterns a metre apart |
| Two **X gantry end plates**, 1/2" | one drawing, right-hand variant carries the BF12 tongue |
| **X carriage plate**, 1/2" | 30 holes |
| **Z plate**, 1/2" | |
| **Interposer bars**, 60 × 150 × 3/8", quantity 3 | six tapped M5 under a bearing face, six flange clearance holes |
| **Both Z spacers** | **face 1 mm off both in the same setup** — see [the Z axis](#6-the-z-axis) |
| Rail mounting patterns, bearing block and nut housing patterns, counterbores | |

| Home drill press | |
|---|---|
| Beam joining plates | 9 mm clearance into T-slots at 150 mm — the T-nut moves to meet the bolt |
| Two **outboard plates**, 11 7/8" × 39 5/16" × 10 gauge steel | ~25 holes each, and steel runs several times longer than aluminium would |
| Three **front strips**, 45 mm × 1 m × 4 mm | |

🔴 **Five plates stand on the box and all five are 301.625 high: the two side plates, the back
plate and the two front fins.** Measure all five against each other as they arrive, before any of
them is drilled. **A part that is not 301.625 is misordered or mismade — send it back.** Two parts
wrong by the same amount would still assemble, so check them against each other and not only
against the number.

**Every hole on those five is measured from the bottom edge**, because the bottom edge is what
bears on the box's top skin. One height and one reference edge is what lines the beam up without
any plate having to know about any other.

**Lay the extrusion bolt patterns out by scribing.** Two lines, four stations ticked along each —
that is the eight-hole pattern at a beam end.

**Each plate only has one WCS origin for the holes to be drilled.** Pick a corner, dimension
every hole from it, never chain dimensions.

**Make one rail the reference and set the second one fastener at a time.** Both rails tap **M5 into
the plate**, so the holes are fixed and nothing is oversized at the mill — the float is the rail's
own, **ø6 through under a ø9.5 counterbore** on an M5. **Lock rail one down completely.** Then work
**along rail two, bolt by bolt**: set parallel at that station with an indicator on rail one's
carriage, tighten that bolt, move to the next. ⚠️ **Never tighten rail two as a set** — it snakes,
and a bolt already home fights the next one you set.

⚠️ **Open: whether the mill can hold one height reference across the 1210.73 mm rear plate.** Bed size is not
travel. The two 8-bolt patterns' relative height must land well inside 1 mm across the metre.
If the part is repositioned mid-job, **indicate the first pattern back in before drilling the second**,
and work from a scribed and indicated line rather than from a sawn edge.

---

## 2. The beams

Three identical stacked pairs — X, Y1 and Y2. Each is two `30-6060` × 1000 mm.

### Load every T-nut first

🔴 **The `13025` T-nut slides in from the end of the slot.** Once a joining plate or an end plate
closes the slot ends, the only way to add one is to take the beam apart.

| Plate | Slots | Per slot | Per beam |
|---|---|---|---|
| Back plate | 4 — full section height | 7 | 28 |
| Front strip | 2 — flanking the seam | 7 | **14** |
| | | | **42 per beam, 126 for the machine** |

**Seven per slot is first at 50 mm, then every 150.**

⚠️ **The front strip's two slots are the ones that get forgotten** while counting out the back, and
they are just as closed once the ends are on. Count them twice.

**Test the slide with one nut before planning the rest of the build.**

The beam ends also take T-nuts for the parts that come later — the **interposer bar** (6 × M8 in the
bottom-face slots at 15 and 45 on Y, the top-face slots on X) and the **shelf bars** on X
(M8 at Y 15 and Y 45 into the bottom extrusion's underside slots). **Those go in now too.**

### Mount the rails

One HGR20 per profile, in that profile's **outside** T-slot — 15 mm in from each outer face of the
120 mm stack, so the two rails end up **90 mm apart**.

| | |
|---|---|
| Fixing | **M5 × 16 into T-nuts**, 17 per rail at 60 mm |
| Hole | ø6 through with a ø9.5 counterbore — M5 socket head. An M6 head will not enter a 9.5 counterbore |

🔴 **Bias every bolt the same direction as you tighten it, and bias both rails the same way.** The
hole is a clearance hole and the T-slot adds more float; tighten 17 bolts with the rail floating and
it snakes. **Common mode — both rails pulled the same way.** Do not pull the two rails apart or
together.

📌 **The X beam's rails are already mounted with an opposed bias** — lower rail toward the lower
edge, upper toward the upper. **Check by feel before redoing 34 bolts**: mount the four blocks to the
carriage plate and slide the assembly the length of the beam. Smooth and even means leave it. A
binding zone tells you roughly where, and only those bolts need revisiting. For a number, put an
indicator on the plate against a straightedge and sweep.

### Join the stack

| | Back | Front |
|---|---|---|
| **X** | 120 mm × 1/4" 6061, full section height | 45 mm × **4 mm** 6061 |
| **Y1, Y2** | no separate back plate — the **outboard plate** is it, see [the Y beam ends](#3-the-y-beam-ends) | 45 mm × **4 mm** 6061 |
| Fixing, back | M8 T-nuts, four rows, 150 mm | — |
| Fixing, front | — | M8 **flange** bolts, two rows, no counterbore |
| Holes | **9 mm clearance** | 9 mm clearance |
| **Bolt** | **M8 × 12** on X · **M8 × 10 + plain washer** on Y | **M8 × 10**, bare |

🔴 **The lengths are not interchangeable, and the long one fails silently.** There is
**1.2 mm of air behind the T-nut** (slot floor measured at 9.5, nut back face at 8.3), so a bolt may
reach at most **7.2 mm** past the back of a plate. **An M8 × 12 in the 4 mm front strip reaches 8.0
and bottoms on the slot floor before its head seats** - it feels tight and the strip is still loose.
Engagement is capped at **6 mm by the nut**, so a longer bolt buys nothing anywhere on this machine.
The washer on the Y back is margin, not decoration: bare, that bolt clears by 0.24 mm if the sheet is
the 11-gauge it was sourced as. Full derivation in
[`gantry-beam-joint.md`](gantry-beam-joint.md#-bolt-lengths-settled-2026-10-04---and-the-slot-depth-is-what-settled-them).

**The buy: 42 × M8 × 10 A4 / 316** (front strips) · **56 × M8 × 10 plain + 56 washers** (Y backs) ·
**28 × M8 × 12** (X back). 126 bolts, 126 T-nuts.

🔴 **The front strip is 4 mm, not 1/4".** At 1/4" the flange head rim passes under the bearing block
and hits — there is at most 6 mm of clearance there, and the 1/4" stack is 7.35.

🔴 **The front strip's 14 flange bolts must be austenitic stainless — A4 / 316.** The magnetic
encoder tape runs on this strip's face, and ferromagnetic bolt heads 1 mm from a magnetic scale put a
periodic error at the bolt spacing into the axis. **42 bolts across the three beams.**

⚠️ **Put a magnet on them when they arrive.** Generic "stainless" bolts bought for this job were
tested and **are magnetic**. 410, 416 and 430 are sold as stainless and are as bad as carbon steel
here. **Ask for A4 rather than A2.** Socket heads are fine if A4 flange heads are awkward to source —
a 13 mm socket head leaves more room for the tape than the flange does.

### 🔴 Assemble the stack against a flat reference

Nothing indexes one profile to the other, and the joining plates lock in whatever they are bolted at.
**Both front faces must end up flush**, or the rails are not coplanar and the carriage plate twists
all four blocks.

**Stack front-face-down on a known-flat surface, or clamp a straightedge across both front faces,
before the joining plate bolts come up tight.** This is the moment the rail geometry is set.

### The magnetic tape

**10 mm tape on the face of the 45 mm front strip**, centred between the two bolt rows. Two rows at
±15 with **13.8 mm** flange heads leaves **16.2 mm clear**. **All three beams carry tape.**

🔴 **The clear lane is sized by the SENSOR, not by the tape.** The AS5311 puck needs **15 mm**
kept clear centred over the tape - the PCB and its mounting points, not the chip - which leaves
**0.6 mm each side**. ⚠️ **At the old 17.3 mm head the lane was 12.7 and the puck did not fit at
all**, which is why the bolt changed. The bolt rows cannot move to help: they are at ±15 because
that is where the extrusion's T-slots are.

🔴 **Bias the strip bolts OUTBOARD as you tighten them.** The holes are ø9 clearance on M8 into
sliding T-nuts, so nothing centres a bolt and ±0.5 is available - both rows drifting inboard takes
the 0.6 down to **0.1**. It costs nothing to push them out, and it is not something to find out
about after the tape is down.

⚠️ **Before 3 m of one-shot PSA goes down:** fit a tape offcut and a sensor and **read at the stepper
end against mid-travel.** A NEMA 23 permanent-magnet rotor sits at the min-Y end of both Y tapes.

⚠️ **Open: the application order.** Either the bolts go in first as a guide channel and the PSA is
threaded into a 12 mm slot, or the tape goes down first against a straightedge and the bolts follow.
Not decided.

---

## 3. The Y beam ends

Each Y beam is carried **at its two ends only** — the ball screw runs underneath it, so nothing can
support it along its length.

### The interposer bar and the cast stepper frame — front end

**One part, quantity 3** (Y1, Y2, X): **60 × 150 × 3/8" 6061**, no counterbores anywhere.

| | |
|---|---|
| Bar to beam | **6 × M8 flange bolts into slide-in T-nuts**, three rows at **82 / 110 / 138** from the bar's outboard end |
| Position | the bar's **outboard end 30 mm past the fin's outer face**, so casting and bar protrude through the window together |
| Casting to bar | its **6 through holes, M5 tapped into the 3/8"** — bar coordinates, columns 7 and 53, rows 28 / 58 / 71 |
| Motor | NEMA 23 onto the casting's own flange |

🔴 **At the Y ends everything below the beam is in tension.** Six M8 hold the bar **up** against the
beam's underside, and the casting is bolted **up** into the bar and hangs from its own M5. Nothing
rests on anything.

⚠️ **The casting's foot is stepped, not one flat plane.** Match or clear the step — if the bar sits
under the stepped portion it holds the casting off its bearing face.

⚠️ **Open on X only: whether all three bolt rows land over beam.** The 82 / 110 / 138 rows came from
Y geometry, and on X the bar sits on top and overhangs the end. **Check before drilling X's bar** —
it is the same part, so the check is on the position, not the drawing.

### BF12 — rear end

**4 × M5 tapped into the inside face of the 1210.73 mm rear plate**, one set per beam. Not
through-bolted.

📌 **BF12's hole count depends on its orientation.** Face-mounted into a plate it is **4 × M5**;
top-mounted down through its base onto a horizontal surface it is **2 × M5**. Any BF12 figure that
does not name the orientation means nothing.

### The front plate — the fin

**Two off, each on its own piece of plate** - they used to nest out of one square: **tapered 100 mm at the top to 200 mm at the base, 301.625 mm
tall, 10 mm** 6061, with a **60.5 × 50 mm window** below the beam for the casting.

The two halves are **rotations of each other, not mirrors** — turn one 180° and the outline is
identical. Left and right come from flipping one plate over.

🔴 **Lay both hole patterns out from the factory vertical edge and the factory top edge.** Each half
keeps one uncut vertical edge and that is the **outboard** one, taper facing inboard. Laid out from
the cut edge instead, the bandsaw kerf becomes a ~1.5 mm offset built into one plate's bolt pattern —
and that pattern has to line up with formed threads in the beam.

⚠️ **Flipping one plate swaps which face is outboard.** Harmless for through holes; check it before
spot-facing or counterboring on one face only.

| | |
|---|---|
| To the beam | **8 × M8 × 35 flange bolts** into the ø6.65 lengthwise corner bores — four per profile |
| Hole | **9 mm**, deliberately. The bores are extruded features and a close fit is impossible in principle |
| M8 columns | **35 and 65 mm** from the factory edge, so the beam spans X 20 to 80 |
| To the box | **two M8 at X 25 and X 170, Y 30** above the plate's bottom edge — these are **L-bracket holes** |

**M8 × 35 leaves 22.3 mm in the extrusion.**

🔴 **There is no front tongue on the box.** The fin sits on the box's **top skin** and **two
L-brackets behind each fin** tie it down, bolting into T1 at X 25 and T2 at X 170. The box runs
**140 mm past the fins**.

⚠️ **Open: the L-bracket itself is not specified** — no size, no fixing into the box. Four are needed.

**Use a steel backing strip or large fender washers on both faces** where these bolts land in
plywood, not plain washers.

### The rear plate

**One plate for both beams: 1210.73 mm × 12" × 1/4" hot-rolled A36 steel**, P&O if mill scale is
unwelcome.

| | |
|---|---|
| To the beams | **8 × M8 into each beam's corner bores** — 16 bolts total |
| To the box | **8 bolts through the back tongue at Y 30**, 150 mm pitch from X 80.365, plus bottom-edge bearing over the full length |
| Also carries | **BF12 on its inside face**, 4 × M5 tapped, one per beam |

🔴 **1210.73 is a reference, not a dimension.** The plate runs flush with the outboard plates' outer
faces, and Sheet 7's X coordinates are absolute from the plate's left edge. **Cut it over-long and
the Y2 station is out by the excess.**

**Buy 60" stock rather than 48".** A 48" sheet is 1219.2 mm and leaves 7.5 mm of trim, which is the
entire margin on a part cut once.

**Clean the mill scale off before paint. Paint is not optional** — this is steel against aluminium
over a metre of contact.

### The outboard plates

**One per Y beam, as ordered: 11 7/8" × 39 5/16" × 10 gauge cold-rolled steel sheet** - 301.625 × 998.54 × 3.429. This **is** the Y back joining
plate — there is no separate 120 mm plate on Y. It runs from the beam down to the torsion box.

| | |
|---|---|
| To the beam | T-nuts along its length, **9 mm clearance** holes |
| To the box | **M8 at 150 mm, first at 50** — seven per beam, at **Y 30** above the plate's bottom edge |
| Direction | from **outboard**: washer, **tongue**, plate, **M8 locknut** on the inboard face |
| Holes | **9 mm clearance** in **tongue** and plate both |
| Position | against the beam's outboard face at X 20, ending **1 mm shy of the beam's end** |

✅ **Settled by the order, 2026-10-08: it is 10 gauge, .135" = 3.429 mm** - not 1/8" (3.175) and
not the "11 gauge" (3.04) the listing also offered. That question stood open for weeks and was
closed by buying the part. The riser-proud check keys off it, and the figure is now **16.571**.
⚠️ **Still caliper what arrives**: a gauge is a nominal, and three nominals on this machine have
already come in wrong.

**Powder coat or paint both faces.** This plate is the chip barrier and it is the part that gets wet
with swarf — aluminium is the anode and the extrusion is what cannot be replaced.

⚠️ **The plate-to-tongue seam is a swarf trap** running the length of the machine. Either seal the top
of it or leave it deliberately open at both ends so it can be blown through.

---

## 4. The X gantry

### The end plates

**Two, 1/2" 6061, 154 mm wide × 242.5 mm tall**, stopping at the top of the X beam. **Identical
below the top edge.** The **right-hand plate only** carries a **BF12 tongue** — 60 across, running to the stock's 300, left uncut — rising off the
top edge, 60 mm wide, with **4 × M5 tapped**.

⚠️ **They are not interchangeable at assembly.** Cut both outlines together and leave the tongue on
one; nothing below the top edge moves.

| | |
|---|---|
| To the X beam | **4 × M8** into the **top** extrusion's corner bores, **9 mm clearance**, both pairs **15 and 45 mm from the plate's back edge** |
| To the Y rails | **four bearing blocks** in a 2 × 2 grid across the full 154 mm — two butted in Y by two rows 90 mm apart |
| ø35 encoder bore | **Y 77, 60 mm below the Y beam top** |

**The bottom extrusion is not bolted to the plate at all.** It sits alongside the Y beam, carried on
a shelf.

⚠️ **The 15 mm to the back edge with a 9 mm hole leaves 10.5 mm of material** — the plate's tightest
edge distance. Do not let that hole drift outboard.

📌 **Scribe and tick the 15/45 pattern**; the ø9 hole on an M8 carries the float.

### The shelf

**One per plate: 1" × 2" aluminium bar — 25.4 wide × 50.8 tall × 60 long**, spanning the beam's
footprint at Y 0 to 60.

**Y is measured from the plate's back edge. Z is from the bar's underside.**

| Hole | Y | Z | |
|---|---|---|---|
| Vertical, counterbored from below | **15** | — | M8 up into a T-nut in the bottom extrusion's underside slot |
| Vertical, counterbored from below | **45** | — | M8 up into the second underside slot |
| Horizontal | **30** | **15** | **M8 × 35** into the end plate |
| Horizontal | **30** | **35** | **M8 × 35** into the end plate |

🔴 **M8 × 35, not × 40.** Through 25.4 mm of bar into 12.7 mm of plate, an M8 × 35 gives ~9.6 mm of
engagement and stops short of the far face. **An M8 × 40 protrudes ~1.6 mm onto the Y bearing block
seat** — the one surface on this plate that has to be flat. **Check the length at assembly.**

⚠️ **Check the counterbore diameter before cutting the bar to exactly 60.** The vertical at Y 15
leaves only ~7.5 mm of wall outside a ø15 counterbore. **65 costs nothing** and still stops short of
the joining plate.

### Hang the beam

**Bolt both end plates on, slide the T-nuts in, drop the beam onto the two shelves, then bolt down.**
One person can do it that way.

⚠️ **The back joining plate's bottom edge must be flush with the beam's underside, not proud.** The
bar passes under where that plate lands.

### The X stepper end

**Interposer on TOP of the beam**, overhanging the end — same 60 × 150 × 3/8" part as Y, same six M8
into slide-in T-nuts. 🔴 **On X the parts are in compression, stacked** — the opposite of the Y ends.

**BF12 face-mounts on the right-hand end plate's tongue**, 4 × M5.

### The X carriage plate

**154 mm W × 407 mm H × 1/2"** 6061 — **30 holes**. It bolts to the four X-axis bearing blocks and
carries the whole Z axis. The blue is layout dye, not a finish.

🔴 **Do not make this joint adjustable.** No set screws over the bearing blocks. The bolt heads are
buried under the Z rails, the screw and the nut housing once assembled, and this joint carries
everything. **Build it solid - everything else is set from it.**

---

## 5. The Y ball nuts

The Y ball nut housings run **inverted** on both beams, so their mounting faces look **down** and
their bolts are reachable.

| Part | Size | Qty |
|---|---|---|
| **Doubler block** | **154 × 45 × 1/2"** 6061, on the end plate's **outer** face at the bottom | 2 |
| **Sole bracket** | **1/4"** 6061 trapezoid, **154 at the root → ~46 at the tip, 98.19 overall** | 2 |

**The doubler gives the plate a 24.38 mm seating at its bottom; the sole bracket bolts up into that.**

🔴 **Two rows of bolts across the 24.38, not one row down the middle.** A single row leaves the joint
nothing to resist rolling about Y.

**The doubler's bolts pass through the end plate along X. The sole bracket's go into the doubler** —
M6 is correct there; nothing from the nut lands in the end plate's edge.

**The nut sits ON the sole plate, bolted up from underneath** — **4 × M5 threaded into the nut body**,
at **±20 mm in X and ±12 mm in Y** about the nut face centre. The nut's mounting face is **40 × 52**,
its long dimension running **along X**.

⚠️ **If "block" in the source meant anything other than the ball nut housing, these four holes are
90° out.** Confirm against the real part before drilling.

⚠️ **Open: the doubler's upper bound is not yet checked on the machine** — the lower Y bearing
block row's bottom edge, computed to land at about −127 from the Y beam top. Same measurement as the
sixteen block holes. **At 45 there is 10.5 of slack against it**, so that measurement would have to
be badly wrong to matter.

---

## 6. The Z axis

| | |
|---|---|
| Fixed | the **X carriage plate**, its two HGR20 400 mm rails, the 1605 screw, the cast frame and BF12 |
| Moving | the Z bearing blocks, the two spacers, the ball nut housing, and the **Z plate** |
| Z plate | **164 mm W × 175 mm H × 1/2"** |
| Spacers | **two lengths of 2" aluminium bar, measured 150.5 and 151.6 long, 16.41 and 16.43 thick** |
| Bolt count | **16 × M5 × 35** — 8 per spacer, 4 per bearing block |
| Fixing | **one M5 per hole does the whole stack** — counterbored in the Z plate, through a 6 mm clearance hole in the spacer, into the bearing block's tapped M5 |
| Travel | **246 mm**, blocks butted |

🔴 **M5 × 35, not × 30.** An M5 × 30 leaves only ~5.9 mm in the bearing block.

🔴 **The Z plate is 164 and the X carriage plate is 154. Do not "tidy" them into line.** At 154
eight of the Z plate's M5 counterbores break out of the edge.

### Face the spacers before assembly

🔴 **The spacer blocks stand higher than the ball nut housing — between 1 and 1.3.** Skim **1 mm off
the spacers, both in the same setup, at the mill**, so they come out identical.

🔴 **Skim 1 mm and no more, even if the step measures 1.3.** The cut cannot be undone. Whatever is
left over gets closed with a shim at the nut, where it can be measured on the assembled machine
instead of guessed at the mill.

🔴 **A full-face shim, not washers.** The shim covers the nut housing's whole 40 × 52 mounting face.
**Washers bear at four points and tilt the housing, which becomes a side load on the screw.**

⚠️ **Measure the step again before cutting**, and **take the ball nut housing to the mill** — the
step is measured against that part.

🔴 **Re-mic both spacers after facing and write the number into the design record.** Everything
downstream of the spacer thickness moves with it, including the spindle offset.

**Do not re-cut the spacers to match each other in length.** Matching matters in **thickness**.
150.5 and 151.6 both cover the M8 rows at ±70.5.

### The top stop

**Two blocks, one per rail, either side of the 60 mm casting** — the casting occupies the middle of
the plate's top edge.

| | |
|---|---|
| Width across the plate | **47 mm** each |
| Front to back | **32.5 mm** — 12.5 of plate plus 20 of rail, so the overhang is flush with the rail top |
| Thickness | **1/4"** |
| Fixing | **2 × M4 × 16 socket head** per block, down into tapped holes in the plate's 12.7 mm top edge |

**M4 not M5** — a 12.7 mm edge leaves 4.35 mm of wall each side of an M4.

🔴 **These are sacrificial.** They fire only if the soft limit and the proximity sensor have both
failed. If one is ever used, replace the block and the bolts. Do not size them by strength.

The block runs **7 mm past the rail end** before contact, against **10 mm** of the block carrying no
balls — measured. The bottom end needs no stop; the nut bottoms on BF12 before the rails run out.

**Keep the plastic arbors** that came with the blocks — they are the transfer and storage tool, and
nothing else substitutes the day one is needed.

### Assembly order

**Rails and spacers first, nut housing last.** The rails define the geometry; the nut follows the
screw rather than being forced into position by its own bolts.

0. **Tap the ball nut housing's four M5 holes from 8 mm deep to 12.** It is aluminium and taps
   easily; the holes are already drilled 16 deep, so there is room. **Blow the chips out.** The four
   bolts into it are **M5 × 16** and they need that depth — at the as-supplied 8 mm they would reach
   less than half the thread aluminium wants.
1. **Bolt the Z plate down onto the spacers and bearing blocks, and torque it.**
2. **Measure the gap at the nut housing with feeler gauges**, with the plate already tight.
3. **Cut a full-face shim to what you read** and fit it behind the housing.
4. **Leave the nut housing's four bolts finger-tight, run the carriage through full travel, then
   torque them.**

🔴 **Never close that gap by tightening the nut's bolts.** The nut cannot move — it is captive on the
screw — so tightening across an open gap pulls the nut off the screw axis and holds it there for
every move the axis makes.

⚠️ **Open: the Z travel floor.** 246 mm is confirmed available, but where that 246 sits relative to
the spoilboard has never been set — material thickness plus tool length plus clearance over
workholding. **This is the one that gets quietly eroded, and it is the one noticed every day.**
It is a machine measurement, taken once the machine stands.

---

---

## 7. Stand it up and measure it

🔴 **The machine is the reference, not the drawing. The box is not built until the whole machine is
assembled on a flat surface and its width measured.**

The machine jigs itself for that measurement, so nothing has to be computed:

| What sets it | How |
|---|---|
| The two Y beams' spacing | the **X gantry** bridging them — its length, its end plates, the bearing block footprint |
| Their coplanarity and parallelism | the **flat surface** they are assembled on, plus the 9 mm reamed holes absorbing the error |
| The box's top skin width | **measured off that assembly**, once it is standing and square |

**Record the measured width in [`../commissioning/`](../commissioning/) before cutting skins.** Do
not let a nominal or catalogue figure substitute for it.

⚠️ **Bias the top skin wide, never narrow.** The skin's width sets the distance between the two
**tongues'** inner faces, and a tongue's inner face is a hard bearing face with no float. A
millimetre or two too wide is a shim; **too narrow and the plates will not fit between the tongues
at all.** They stand on the top skin and are lapped from outboard - nothing drops into a groove,
but the gap is still a hard dimension.

---

## 8. The torsion box

| | |
|---|---|
| Skins | **19 mm Baltic birch** top and bottom — **25 mm top over 19 mm bottom** if anything is spent |
| Grid | **19 mm strips, 100 mm high**, **egg crate** — continuous both ways, half-depth notches at every crossing |
| Depth overall | **138 mm** |
| Outer walls, all four sides | **two 19 mm laminations, 38 mm total** — the outer one 180 mm tall, standing on the bottom skin and **60 mm proud** of the top skin as a **tongue** |
| Footprint | **1210.73 across** by **1156.35 front to back** — ⚠️ derived, verify against the standing machine |
| Fill | **sand in the cavities, LAST, on site** |

### Four things to get right on the grid

1. ⚠️ **Cut the notches to the measured sheet thickness, not to 19 mm.** Baltic birch sold as 19 mm
   is commonly 18.2-18.5 and varies between sheets. **Test-cut on scrap from the same sheet.**
2. ⚠️ **Notch depth exactly half.** A set cut slightly deep sits low and loses contact with a skin
   along its whole length.
3. 🔴 **Notch the bottom edge of every rib where it meets the bottom skin, roughly 20 × 15 mm.** An
   egg crate seals every cell; without this each cell traps its own sand and needs its own drain port.
4. **Clamp the skins hard onto the rib edges.** Screws through the skins into the ribs give uniform
   pressure and can stay in.

**Assemble the grid and check it flat on a reference before either skin goes on** — an egg crate
self-jigs and holds its own spacing with no clamps.

⚠️ **Open: the grid spacing.** Conventional is 200-300 mm. Two constraints: the **first interior rib
in from each perimeter must clear the front corner tenons**, and the **two front-to-back ribs either
side of the back-centre tenon must clear its 86 mm width**. Let the spacing bend to the back-centre
tenon.

⚠️ **Blocking has to be in the rib layout under the 200 mm fin bases and under the full 1210.73 mm
of the rear plate's bottom edge** — bottom-edge bearing is only worth having if it lands on structure
rather than on skin spanning between grid members.

### The three posts

**Front left corner, front right corner, and the middle of the back.** Each an **86 mm square cedar
post (4×4)**, reduced over its **top 118 mm** to a tenon that passes up through a hole in the bottom
skin. The bottom skin lands on the shoulder.

| | |
|---|---|
| Ledge to top of post | 118 mm |
| Bottom skin on the ledge | 19 mm |
| Cavity | 100 mm |
| Underside of the top skin | **119 mm** — so the post top stops **1 mm shy** |

**Every ledge is 38 mm, cut on the outward-facing faces**, so the perimeter wall lands directly over
the shoulder.

| Post | Faces ledged | Tenon |
|---|---|---|
| Front left / front right | the **side** face and the **front** face | **48 × 48** |
| Back centre | the **back** face | **86 × 48** |

⚠️ **Cut each hole to its own post.** 86 mm is the working figure; S4S 4×4 is commonly 88.9 and
cedar varies between sticks. **Measure the three you have** — a 38 mm ledge on two adjacent faces of
an 88.9 stick leaves ~51 mm, not 48.

🔴 **Drive one screw at an angle into the side of each tenon, from inside the cavity, BEFORE the top
skin is glued.** After that there is no access to those tenons ever again. Not a vertical bolt down
through the shoulder — that is withdrawal from cedar end grain.

**The box is not otherwise fastened to the posts.** Gravity and 99 mm of tenon engagement hold it.

### Drain ports

**Low in the front and back perimeter walls.** They gravity-drain into a bucket and stay reachable.

🔴 **Not in the bottom skin** — the 2x4 frame and three carcases make it unreachable.
⚠️ **Not in the laminated left and right walls** — those are the 38 mm webs the Y beam plates bolt to.

### The base

| Member | |
|---|---|
| **2x6 bottom frame** | locates the posts, **5/16" bolts** through post and frame, **two minimum per joint**. It is also the pallet |
| Clearance beneath | high enough for a **pallet jack to enter and lift** |
| **2x4 top frame** | ties the post tops together, the top chord for the shear walls. Sits **just shy of the bottom of the box** |
| **Shear walls** | three plywood cabinet carcases — rear left, rear right, and one across the front between the two front posts, all openings facing **out** |

🔴 **The 2x4 top frame must never touch the box.** The moment it does there is a fourth and fifth
contact point, the mount is no longer three-point, **and the failure is completely silent** — nothing
but the Y beams drifting out of coplanar.

- **Clearance 10 mm or more**, not 1 mm.
- **Keep the gap inspectable** — a feeler or a strip of paper must slide between box and frame at
  several points, years from now.
- For transport, use **removable packers** set on the 2x4 frame, taken out on arrival. Not a
  permanent catch.

⚠️ **Open: the box's deflection between its three points under full sand load.** It sets the minimum
clearance and needs the grid spacing and the sand mass first. **The one number here that a wrong
guess would quietly cost accuracy for.**

🔴 **Edge fastening is what makes a shear wall a shear wall.** **Glue plus screws at roughly 150 mm
all the way round** — to the bottom frame, the top frame, the posts, and carcase to carcase where
they meet. A carcase that merely sits in the void with screws in its corners contributes close to
nothing **and looks identical to one that works.**

⚠️ **Open: where the stabiliser legs go.** Whatever they are, they must be set **deliberately
short** — if they carry load it is no longer a three-point mount.

---

## 9. Set the machine on the box

Both the front fin and the outboard plate land on the **same top skin**. **The fin sets the beam
height and the two beams' coplanarity, so the fin is the reference for the pair and the plate follows it.**

| Part | How it lands |
|---|---|
| **Front fin** | bottom edge **bearing on the top skin**; **two L-brackets behind it** into T1 and T2 |
| **Outboard plate** | bottom edge bearing on the top skin directly over the wall; outer face **bearing against the side tongue's inner face**; **seven M8 from outboard** into locknuts |
| **Rear plate** | bottom edge bearing over the full 1210.73 mm; **eight bolts through the back tongue at Y 30** |

**The side tongue runs 1000 mm, starting 1/4" from the box's back edge** — so it spans exactly the
beam and the side plate it laps, and ends where the fin begins.

⚠️ **The front and back tongue arrangement is inconsistent between the design record and the shop
pack.** The shop pack (2026-10-03, the later of the two) says **there is no front tongue** and the
fin is tied by L-brackets; [`torsion-box.md`](torsion-box.md) and
[`lateral-stiffness.md`](lateral-stiffness.md) still describe a continuous front tongue lapping the
side tongues. **Resolve before the walls are glued up.**

## 10. Fit the spindle and tram

| | |
|---|---|
| Spindle | **Ø80 × 213 mm, 2.2 kW, 220 V, 8 A, 400 Hz** water-cooled, RATTMMOTOR, with VFD, ER20 collet and pump |
| Mass | **5.2 kg** |
| Clamps | **two 80 mm aluminium clamps**, 120 × 55 × 100 mm, one at each end of the barrel |
| Clamp centres | **116 mm** — mid-height at ±58 mm from plate centre |
| Fixing | **4 × M8 × 80 socket head** per clamp, into **tapped** holes in the Z plate |
| M8 rows | **17 and 42 mm from the nearer plate end** ← the drilling dimension |
| Water | two **Ø8 mm** fittings, exiting radially at the rear |

**Orientation: the clamp's 100 mm dimension is front-to-back**, with the 80 mm bore centred in it.
55 mm is axial.

🔴 **Torque the clamp bolts to ~15 N·m, NOT the ~25 N·m an M8 8.8 would take.** 10 mm of engagement
in 6061 is the limit, not the bolt. **Four M8 helicoils per clamp position** takes it to full spec if
you would rather not have to remember.

🔴 **Never shim the two clamps against each other.** They bore a round body and must stay coaxial.

**Measure on arrival:** where the water fittings and cable exit sit, the body diameter over the whole
clamping length, and the weight.

### 🔴 Tram here, with the machine bolted down

🔴 **Tram is set on the installed machine** — standing on the box, bolted to the tongues, in the
position it will run in. Tramming a free-standing assembly sets it against a reference the machine
does not have yet.

**It is set once, and only with the clamps off** — all 16 M8 are accessible only then. There is no
sub-plate and no permanent jacking provision, so redoing it later means lifting the spindle out of
its two clamps.

| Rotation | Where it is taken |
|---|---|
| **Roll** | **Shim between the shelf bar's top face and the X beam's bottom extrusion**, at one end plate only. Shim the low end |
| **Nod** | At the Z plate, using the two outermost M8 rows — one as the hinge, the other as the adjuster. The two middle rows are torqued once the tilt is set |
| Yaw | Does nothing on a round spindle |

**Roll shim stock: 1" wide aluminium strip**, which is exactly the bar's 25.4 width — a strip cut to
the bar's 60 mm length is a full-face shim. **0.03 mm of shim moves tram by 0.003 mm per 100 mm.**

🔴 **Slot the roll shim open from one edge at Y 15 and Y 45**, so it slides in with the two vertical
M8 loosened rather than removed. A plain rectangle means pulling the beam off.

**Order of work for roll: loosen the four M8, slide the shim in, re-torque.**

⚠️ **Range is capped at about 0.5 mm by the 9 mm bolt clearance**, so the beam is deliberately not
centred in those holes once shimmed.

**For nod, use a row and not a column**, and use the two outermost rows — angular resolution is jack
travel over row separation. **Every bolt above the hinge has to be free** while the tilt is set.

### Then run the stiffness test

**It pushes on the spindle nose, so it cannot run before this stage**, and it is run on the
machine bolted down in its installed position — the condition worth measuring.

📋 **Procedure: [`../commissioning/stiffness-test.md`](../commissioning/stiffness-test.md).** Six
indicator positions and a subtraction — **do not improvise it at the machine.** One reading on the
spindle nose is a total, and a total cannot say which part of the stack is moving.

It settles two deferred decisions: whether the X gantry back plate goes from 1/4" to 3/8", and
whether the X carriage plate goes from 1/2" to 5/8". ⚠️ **Do not act on either before the test.**
If the carriage plate does move, it goes to **thicker aluminium, not a bolted-on steel backer.**

---

## 11. Fill the sand

**Last, on site.** Roughly 165 lb. Everything above it has to be finished first, and dumping it is
the single biggest lever on ever moving the machine.

### If the machine is moved

| Interface | How it is held |
|---|---|
| Frame to posts | **5/16" bolts** — positive |
| **Posts to box** | **gravity and 99 mm of tenon** — the only non-positive joint in the stack |
| Carcases to frames and posts | glued and screwed — positive |

- **Two straps over the box, down to the 2x6 frame.** This is the restraint to rely on, not the
  tenon screws.
- **Put the fork positions under or very near the three posts.** Add a cross member where the forks
  land if the layout does not cooperate.
- **Drain the sand.** ~240 lb box becomes ~73 lb.
- **The CG is high.** Long axis fore-aft, strapped. **Tipping is the hazard, not weight.**
- **Set the removable packers on the 2x4 frame** before the move; take them out on arrival.

**Weigh the assembly on a weighing pallet jack** when it is built, and put the figure in
[`../commissioning/`](../commissioning/).

---

## Still open

Everything marked ⚠️ above, and in full in [`open-items.md`](open-items.md). The ones that gate
cutting or drilling:

| | |
|---|---|
| The **4 × HGH20 block hole pattern** measured on the **X/Y** kit — not the Z kit | gates the sixteen M5 in each X end plate |
| Whether the mill holds one height reference across **1210.73 mm** | gates the rear plate |
| Whether X's interposer rows at **82 / 110 / 138** all land over beam | gates X's bar |
| The **grid spacing**, and the box's deflection between its three points | gates the skins and the 2x4 clearance |
| The front/back **tongue** inconsistency | gates the box walls |
| The **L-bracket** specification | gates the fin fixing |
| How far past the front riser plane the **spindle** reaches | gates the fin's taper cut |
| The **Z travel floor** against the spoilboard | a machine measurement, taken once it stands |
| Whether the **stiffness test wants the sand in** | the order above runs it at stage 10 and fills at stage 11, because the sand is specified as last. Nothing states whether 165 lb of base mass changes the reading |
| **Torque figures** — only the spindle clamp's ~15 N·m is specified anywhere in this repo | |

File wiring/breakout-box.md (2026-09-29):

# The remote breakout box

Every per-axis connection terminates here rather than on the controller box's back panel. The
controller box keeps the logic and nothing else - it does not even hold its own supply.

Settled 2026-09-10. Decisions, not measurements; nothing has been built or metered.

## What is in it

| | |
|---|---|
| **48 V, 600 W** power supply | Motor power. 12.5 A across all axes |
| **12 V, 3 A** buck | Limit sensors, and the relays in the controller box |
| **5 V, 3 A** buck | The controller box's logic supply |
| **DB37 breakout board** | Fans the [DB37 interconnect](db37-axis-interconnect.md) out to the back-panel connectors |

**The boxes share a common ground.** The 5 V and 12 V returns, the DB37 per-axis GNDs and the 48 V
return are all one node - which is what makes a single GND per axis in the DB37 sufficient, and
also what makes the next section matter.

## ⚠️ Star the 48 V returns

**The one wiring order that decides whether the signals are clean.**

Each axis's GND sits in the same 6-pin shell as its 48 V, so that conductor carries motor return
current - several amps, chopped by the drive - and it is *also* the reference the drive's optos are
commoned to.

- **Right:** every stepper GND lands on the **PSU negative terminal directly**. Motor current never
  crosses the signal reference.
- **Wrong:** the stepper GNDs daisy-chain through the DB37 breakout board's ground terminals. Then
  the IR drop from every axis's motor current appears as common mode on Step, Dir, AL and Limit.

Same parts, same cost, same afternoon. Only the order the rings go onto the stud differs. Written
down because the wrong version works fine on the bench with the motors idle.

For contrast, the controller's 5 V return *does* run in parallel with the five DB37 GND pins, and
that is fine: at plausible gauges it puts the two ground nodes tens of millivolts apart, against an
opto threshold of about 1.2 V. Not worth engineering around.

## Back panel - Molex Mini-Fit Jr, panel-mount female

Two connectors per axis.

### Stepper, 6P

**AL, EN, Step, Dir, 48 V, GND** - on **18 AWG**, 6 conductor.

The steppers are **integrated closed-loop units**: the drive is at the motor, so what leaves the box
is logic plus motor supply, not motor phases.

> **If the steppers were ordinary open-loop motors**, the drivers would sit in the breakout box and
> this same 6P shell would carry **AL, EN, A+, A−, B+, B−** - phases, not logic. Recorded because
> the connector count and the cable are identical, so a future swap looks like a drop-in and is not
> one: it moves the switching currents out onto the drag-chain cable.

### Limit, 3P

**12 V, Limit, GND** - three-wire inductive proximity sensor, powered from the 12 V buck.

The part is an **SN04-N** (Haldzemo, 4-pack). Datasheet in
[`../manufacturer-assets/`](../manufacturer-assets/) - read off the drawing, not the listing:

| | |
|---|---|
| Supply | 6-36 V DC. **12 V is inside range** |
| Output | **NPN, normally open.** Open collector - "switched negative" |
| Max load | 300 mA |
| Response frequency | **500 Hz** |
| Detect range | 0-4 mm, non-shielded |
| Captive cable | **1.2 m** |
| Protection | IP67 |

Wire colours: **brown = +V, black = output, blue = 0 V.**

**There is no internal pull-up.** The datasheet's terminal drawing puts the load between black and
+V, and the NPN configuration page draws the output as a plain switch to 0 V. So the black wire is
free to be pulled up to whatever rail the controller wants - which matters, because of the next
part.

### ⚠️ Do not copy the datasheet's MCU circuit

Page 3 of the datasheet shows the sensor driven into an Arduino as: **1 kΩ pull-up to +12 V**, then
a **3.3 kΩ / 2.2 kΩ divider**, giving the **0-4.8 V** the drawing labels. That is sized for a 5 V
Arduino.

**4.8 V into a Teensy 4.1 pin destroys it** - the iMXRT1062 is a 3.3 V part and is not 5 V tolerant.

Since the output is open collector with no internal pull-up, the whole divider is unnecessary:
**pull the black wire up to the controller's own logic rail and stop.** No 12 V ever appears on the
signal, and there is nothing to get the ratio wrong on. Use **1 kΩ-2.2 kΩ** rather than an MCU
internal pull-up - the run is a drag-chain cable plus 1.5 m of DB37, and a 20-50 kΩ internal
pull-up leaves it high-impedance next to Y Step
([see the adjacency](db37-axis-interconnect.md#-two-steplimit-adjacencies-known-and-accepted)).
The sensor sinks 300 mA, so the resistor value is not remotely a constraint.

### ⚠️ The 1.2 m captive cable does not reach

Each sensor ships with **1.2 m** of moulded-on lead. That is the axis end to somewhere near the
axis end - not to the breakout box. Every limit needs a junction near its sensor, and that junction
is then in the drag chain's environment. Not yet designed.

## ⚠️ NPN-NO conflicts with the fail-closed argument

The sensors fitted are **normally open**. [`design-can-position-feedback.md`](../linear-encoder/design-can-position-feedback.md)
§3 settles the limit sense as **NC**, and the whole of its argument is fail direction:

| | NPN-NC | NPN-NO (fitted) |
|---|---|---|
| Broken signal wire | reads **triggered** - stops | reads clear - **drives on** |
| Dead sensor / no 12 V | reads **triggered** - stops | reads clear - **drives on** |
| Connector pulled | reads **triggered** - stops | reads clear - **drives on** |

Recorded as fitted, not re-argued. `$5` inverts the sense in firmware so either part *works*; no
setting recovers the fail direction. The consequence is written here so it is a known property of
the machine rather than something discovered during a crash.

**It also removes a property the DB37 was getting for free.** With NC limits, pulling the
interconnect faulted the machine. With NO it does not.

**The drop-in NC part exists.** The same body, bracket, cable and wire colours are sold as
**SN04-N2** - the series runs N (NPN NO) / N2 (NPN NC) / P (PNP NO) / P2 (PNP NC). Recorded so the
option is known, not to reopen the choice: swapping restores fail-closed and changes nothing else
in this document.

## Sensor response latency

**500 Hz** response frequency is a **2 ms** worst case before the output moves. At the 16 k rapid
the encoder design doc uses for its own latency argument - 267 mm/s - the axis travels about
**0.53 mm** in that window, before anything downstream has been told.

Recorded because this repo cares about where travel numbers come from. It is not an objection: the
sensor is the backstop, and 0.5 mm of it is the cost.

## The drives are HBT57C - and three things follow

Added 2026-09-29, from notes written in an ioSender session on 2026-09-26. **Not yet folded in
properly** - the full HBT57C material (LED fault codes, the ENA-reset question, $744/$745) is
scheduled to land in this folder and has not. Until it does, the memory note is the fuller source.

**TOSEASTARS HBT57C**, 57 frame / NEMA 23, 24-55 V DC, 36 V recommended. The manual is not in
[`../manufacturer-assets/`](../manufacturer-assets/) yet, which this repo's own rule says it should
be.

### ⚠️ AL has no pull-up today, which is why it has never asserted

Pins 11/12 are **AL+ / AL-**, open collector, max pull-up 24 V / 100 mA. AL+ is the collector and
AL- the emitter, so it is a **floating switch** - tying AL- to the shared GND at the connector is
what makes the single-GND scheme on this page work for it.

**An open collector with nothing pulling it up never shows a level.** There is no pull-up in the
build today, and that alone accounts for the alarm never having been seen to work. It needs one,
and — exactly as for the limit sensors above — **not the manual's 24 V / 2 kΩ near a Teensy pin.**

### ⚠️ AL fails open, so it is not a guard on its own

Fault means the transistor conducts and the line goes low. But **a drive with no power, or a broken
AL wire, leaves the transistor off** - the pull-up wins, the line reads high, and that reads as
*healthy*. A dead or unplugged drive looks fine.

It becomes a real guard only when paired with a **driver-power-present** input: *power present AND
no alarm* = healthy. Neither half is sufficient. **There is no pin allocated for that signal** -
it is a candidate for the seven spares in
[`db37-axis-interconnect.md`](db37-axis-interconnect.md).

This is the same failure direction as the NO limit sensors above. Two of the three things that are
supposed to stop this machine currently fail silent.

### ⚠️ Do not daisy-chain the 48 V

The manual is explicit: *"parallel connection should be adopted at the power supply, and chain
connection from one driver to another is not allowed."* A chained rail makes both over- and
under-voltage trips far likelier at the far end.

So the star rule above is **not only about the returns** - the 48 V positive runs from the PSU to
each drive as its own leg too. Never verified against how the machine is actually wired today.

### Note on the five AL pins

grblHAL has **$744 / $745** and raises **Alarm 17, motor fault**, and the core defines *per-axis*
fault inputs. But the Teensy driver implements only a **single combined** motor-fault pin across
every board map - so five separate AL conductors are ahead of the firmware, and today they would
have to be wire-ORed into one input.

Keeping them separate in the connector is still the right call: the wiring is nearly free during a
build and impossible to retrofit cheaply, and per-axis needs only a board-map edit later. Recorded
so the gap is not mistaken for a wiring error.

## ⚠️ Open

1. **Controller draw on the 5 V rail.** The buck is rated 3 A; the actual draw, and the gauge of the
   5 V pair, are not established. Both are needed before the drop across that run means anything.
2. **Which rail the limit pull-up goes to.** Follows from the controller board's input stage - 3.3 V
   direct, or 5 V if its inputs are buffered. The breakout box has 5 V but not 3.3 V, so this also
   decides whether the resistor sits in the breakout box or at the controller.
3. **48 V against a 55 V over-voltage trip.** The drives trip on over-voltage at a figure the manual
   states three ways; the memory note says design to **55 V**. A 48 V rail leaves about **7 V** of
   headroom for regeneration on decel. No regen fault has ever been observed - but it is not
   recorded what supply voltage that history was accumulated at, and 48 V is a swap-in. Establish
   the present rail voltage before treating the clean history as applying.
4. **Peak current per axis on 18 AWG.** 18 AWG is about 21 mΩ/m; the drag-chain run length and the
   drive's peak draw are both unrecorded, so the drop is uncomputed.
5. **Where the drives' opto commons sit.** The HBT57C signal pins are **pairs** - PUL+/PUL-,
   DIR+/DIR-, EN+/EN-, AL+/AL-. The six-wire scheme on this page ties all four minus legs to the
   shared GND at the connector, which is standard common-cathode practice and is what the AL
   wire-OR already does. **It is still an assumption**, and it is the one everything else here
   rests on. Confirm against the manual once that is committed.
6. **EN polarity.** Genuinely ambiguous in the manual - the FAQ says a low enable prevents motion
   and that it should be "pulled high or not connected", but it is an opto input where floating
   means no current. **Measure, do not reason.** The manual also recommends leaving EN
   unconnected, so they are probably floating on the machine today.
7. **The limit sensor junction.** See the 1.2 m cable above - needed per axis, not yet designed.
8. **Target plates.** 4 mm non-shielded sensing means something ferrous has to come within 4 mm at
   each end of travel. Not yet specified.
9. **The HBT57C manual is not committed.** Per this repo's datasheets-committed rule it belongs in
   [`../manufacturer-assets/`](../manufacturer-assets/), and several items above cannot be closed
   without it.

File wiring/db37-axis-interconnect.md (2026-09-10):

# The DB37 axis interconnect

The per-axis back-panel connections live in a **remote breakout box**, not on the controller box.
One **1.5 m DB37 cable** carries every axis signal between the two.

**DB37 female at both boxes**, so the cable is male-male. That is deliberate: a symmetric M-M lead
cannot be plugged in the wrong way round, and there is only one cable to get wrong.

Settled 2026-09-10. The pinout below is a decision, not a measurement - nothing here has been built
or metered yet.

## Six conductors per axis

| | Direction | Notes |
|---|---|---|
| **Step** | controller → driver | The fast edge. The only real aggressor on the cable |
| **Dir** | controller → driver | |
| **EN** | controller → driver | Per axis, not commoned across drivers |
| **GND** | shared | The commoned cathode rail - see below |
| **AL** | driver → controller | Closed-loop driver alarm |
| **Limit** | switch → controller | **NC.** See [fail-closed](#the-connector-fails-in-the-right-direction) |

The driver's Step/Dir/EN inputs are **opto pairs wired common-cathode (sinking)**: the `-` side of
each opto is tied to the shared GND and the controller sources current into the `+` side. That is
what makes a single GND per axis sufficient - it is not just a return, it is the reference the
optos are commoned to.

## The pinout

Five axis blocks. Four are in use (X, Y, A, Z); **B is wired and unused**, so a fifth motor channel
costs a plug, not a re-terminate.

Five blocks of six is **30 pins of 37**, leaving **7 spare**.

### Row A - pins 1-19

| Axis | Step | Dir | EN | GND | AL | Limit |
|---|---|---|---|---|---|---|
| **X** | 1 | 2 | 3 | 4 | 5 | 6 |
| **Y** | 7 | 8 | 9 | 10 | 11 | 12 |
| **A** (Y2, M3) | 13 | 14 | 15 | 16 | 17 | 18 |

Pin **19** - spare

### Row B - pins 20-37

| Axis | Step | Dir | EN | GND | AL | Limit |
|---|---|---|---|---|---|---|
| **Z** | 20 | 21 | 22 | 23 | 24 | 25 |
| **B** (M4, reserved) | 26 | 27 | 28 | 29 | 30 | 31 |

Pins **32-37** - spare

## Why the map looks like this

### One contiguous block per axis

Each axis is an unbroken run of six pins, so one field cable maps to one range. It is wired in
order, labelled in order, and fault-found with a meter by counting rather than by reading a table.
Any scheme that interleaved axes would trade that away for a noise margin this run does not need.

### GND at position 4

With **one** shared return per axis its position is a compromise, and putting it in the middle
minimises the worst-case loop area for any signal in the block. It also lands between the three
driven outputs and the two sensed inputs.

This is a second-order effect at 1.5 m behind a shield. It is done because it is free, not because
it is load-bearing.

### One GND per axis, and what it trades

The alternative - a return conductor adjacent to every signal - would have used all 37 pins and
left nothing for a fifth axis. **The fifth axis won.** The shield and the short run are doing the
noise work here; the returns are doing the referencing.

Chosen deliberately, so it does not want re-arguing. What it costs is documented below.

### ⚠️ Two Step/Limit adjacencies, known and accepted

The DB37's rows are staggered - **pin 20 sits physically between pins 1 and 2** - so a block in row
B straddles two blocks in row A. Physical neighbours are diagonal, not numeric.

That leaves two places where a fast output sits next to a high-impedance input:

| | is physically next to | |
|---|---|---|
| Pin 25 - **Z Limit** | ↔ | Pin 7 - **Y Step** |
| Pin 31 - **B Limit** | ↔ | Pin 13 - **A Step** |

With 30 of 37 pins spoken for there is no slack to guard both, and shuffling the map to dodge them
would cost the contiguous-block property that makes it wirable. Written down because a phantom hard
limit on Z or B is the failure this would produce, and it reads exactly like a mechanical fault -
which sends you to the gantry instead of to the cable.

**B is unused, so in practice only the Z one is live.**

## The cable

The cable decides whether this works. Ordering by pin count alone is how it goes wrong.

- **Straight-through, pin 1 ↔ pin 1.** Some DB37 M-M leads are wired crossover. Verify from the
  datasheet, not the listing title.
- **Overall braid shield, bonded to the metal backshell** at both ends. Both boxes share a safety
  earth, so a chassis-to-chassis bond over 1.5 m is what you want - not a single-ended shield.
- Not ribbon.

## The two cables that run beside it

The DB37 is not the only thing between the boxes. The breakout box holds the supplies, so it feeds
the controller box rather than the other way round:

| Cable | Carries | For |
|---|---|---|
| **DB37** | The 30 axis signals above | |
| **5 V + GND** | From the 5 V / 3 A buck | The controller box's logic supply |
| **12 V + GND** | From the 12 V / 3 A buck | The relays in the controller box |

**The boxes share a common ground.** That is what makes one GND per axis sufficient here - the DB37
grounds are a reference, not the only return path.

It also means the 5 V return runs in parallel with the five DB37 GND pins. That is fine: at
plausible gauges it puts the two ground nodes tens of millivolts apart, against an opto threshold of
about 1.2 V. The ground arrangement that *does* matter is in [`breakout-box.md`](breakout-box.md).

## ⚠️ The connector no longer fails safe

**This section previously claimed the opposite**, written while
[`../linear-encoder/design-can-position-feedback.md`](../linear-encoder/design-can-position-feedback.md)
§3's **NC** decision was assumed to hold. The sensors actually fitted are **SN04-N: NPN, normally
open** - see [`breakout-box.md`](breakout-box.md).

With NC limits, pulling this connector opened every limit at once and faulted the machine, and
concentrating five axes into one shell cost nothing. **With NO limits it does.** A DB37 that is
unplugged, half-seated, or has a broken limit conductor reads *clear* on every axis at once, and the
machine will drive into a stop.

Nothing about the pinout changes. What changes is that this connector is now a single point whose
failure is **silent** - so it wants screw locks at both ends, and a homing cycle treated as the test
that it is seated.

## ⚠️ Open

Not guessed. Each needs an answer off the bench before the box is built.

1. **Controller-side source current.** Common-cathode means the controller *sources* the opto
   current, typically 8-16 mA per input. What buffers the Teensy's 3.3 V pins has not been checked.
   The failure signature is Step working at low feed and dropping pulses at high - meter it before
   trusting it.
2. **Spare pin allocation.** Seven pins (19, 32-37) are unassigned. Probe, spindle and E-stop have
   not been considered against them.

**Answered since first written:** what terminates in the breakout box, and where the drivers sit -
both in [`breakout-box.md`](breakout-box.md). The drivers are **at the motors**; the steppers are
integrated closed-loop units, so this cable carries logic and never motor phases.

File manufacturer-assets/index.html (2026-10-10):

# Manufacturer assets

Third-party datasheets, schematics and documentation for parts used in this build. The files themselves are deliberately untracked — they are other people's copyrighted documents and this repository is public. This index is tracked, so the files can always be fetched again.

If the folder is empty (fresh clone, or a file went missing), download each asset from the URL below into this folder, using the filename in the File column. Documents referenced elsewhere in this repo expect those exact names.

Part | Vendor | What it is | File | Source | Captured
AS5311 | ams-OSRAM | Datasheet, rev 1.12 — the magnetic linear encoder used on all axes. Pin table, the Red/Yellow/Green field decode, and the Hall-array location in Figure 14 that the sensor board's layout depends on. | AS5311-Datasheet.pdf | download.mikroe.com/documents/datasheets/AS5311.pdf | 2026-08-25
ESP32-S3-RS485-CAN | Waveshare | Board schematic — the only place the 20-pin header's GPIO map is published. The vendor wiki documents just the 4-pin SH1.0 connector, which is why this was hard to find the first time and is worth keeping. | ESP32-S3-RS485-CAN-Schematic.pdf | files.waveshare.com/wiki/ESP32-S3-RS485-CAN/ESP32-S3-RS485-CAN-Schematic.pdf | 2026-08-25
69255-004LF | Amphenol ICC (FCI) | RJ45 modular jack, 8P8C — vertical, unshielded, through-hole, no integrated magnetics. The sensor-board connector: unshielded is what keeps the cable screen grounded at the controller end only, and no magnetics is what lets DC-coupled signals through. | Amphenol-69255-RJ45-Vertical-Unshielded.pdf | cdn.amphenol-cs.com/media/wysiwyg/files/drawing/69255.pdf browser only — reached via the Mouser product page (https://www.mouser.com/ProductDetail/Amphenol-FCI/69255-004LF). | not captured dimensions read from the drawing by hand 2026-08-25 (DIM C = 15.62 mm)
SN04-N | Handson Technology (sold as Haldzemo) | Inductive proximity sensor, 4 mm, IP67 — the axis limit sensors. NPN normally open, 6–36 V, 300 mA, 500 Hz, 1.2 m captive cable. Page 3 carries the terminal assignment (brown = +V, black = output, blue = 0 V) and page 4 the NPN/PNP drawing that together prove the output is open collector with no internal pull-up. Page 3's Arduino circuit yields 4.8 V and must not be copied onto a 3.3 V controller — see wiring/breakout-box.md. | SN04-Proximity-Sensor-Datasheet.pdf | handsontec.com/dataspecs/sensor/SN04-Metal Detector.pdf | 2026-09-10
Φ80×213 2.2 kW | RATTMMOTOR | Water-cooled spindle kit — spindle, 2.2 kW VFD, 80 mm clamp, ER20 collet, pump. 220 V, 8 A, 400 Hz, 24 000 rpm, 5.2 kg, stainless body, 4 bearings P4 class, grease. Runout < 0.01 mm, tapered bore 0.003–0.005 mm. The nameplate reads Φ80×213, against the 199 mm body this repo had been designing to — a 14 mm disagreement that must be settled with a tape on the real part, not from either drawing. The listing's own drawing also shows 27 mm at the rear and 33 mm across the collet nut. See machine/end-plates-risers-and-spindle.md. | Spindle-2.2kW-80mm-RATTMMOTOR-listing.png | Amazon listing, RATTMMOTOR store — parameters image. | 2026-10-02 screen capture, not a vendor datasheet

HGH20CA

Vevor

Linear guide block, HGH-CA series size table. The row this machine runs on: H 30, H1 4.6, N 12, W 44, B 32, B1 6, C 36, L1 50.5, L 76.7, K1 12.25, G 12, T 8, H2 6, H3 6. Load ratings C 17.75 kN dynamic, Ca 27.76 kN static. The tapped hole is Mxl = M5 × 6 — the THREAD is 6 mm deep, and the 8 is T, the hole depth, which agrees with a measured 8.7. That distinction decides the Z carriage bolt length; see machine/z-carriage.md. L = 76.7 disagrees with a measured butted pair of 154.18 (77.09 each) by 0.39. The same table gives the rail side: WR 20, HR 17.5, D 9.5, h 8.5, d 6, P 60, e 20, mounting bolt M5 × 16.

Vevor-HGH_Spec.jpg

Printed manual supplied with the rail kit, page 10.

2026-10-08
photograph of a paper page
HGH20 rail | Vevor | Linear guideway rail dimensions. WR 20, HR 17.5, P 60, E 20, 2.29 kg/m. Lengths offered: 600, 700, 1000, 1200, 1500, 1700, 2000. 🔴 THIS PAGE CONTRADICTS THE BLOCK PAGE ON THE MOUNTING BOLT. It gives S = M6 × 1P and h = 10 where the block page gives M5 × 16 with D 9.5 / h 8.5 / d 6. A ø6 through-hole cannot pass an M6, so the block page is self-consistent and this one is suspect — but 14 tapped holes on Sheet 3a depend on the answer and it is settled by calipering the rail's own through-hole, not by argument. | Vevor-LinearRail_Spec.jpg | Printed manual supplied with the rail kit, page 9. | 2026-10-08 photograph of a paper page

DSG1605

Vevor

Ball nut housing for a 1605 screw — part name DSG 16 H. D 28, B 52, H 40, h 20, E 12, L 40, C1 8, C2 24, P 40, X M5, øW 38, Y M5, with 6‑Y on the face. h = 20 is the screw axis above the mounting face — the same convention as BK‑12 and BF‑12's h = 25, and it checks out against H = 40, the bore being centred across that width. It is the number the X and Y nut heights are built on. The page carries TWO hole patterns and they are different joints. The 6‑Y on the ø38 circle, middle view, is the housing bolting to the SFU ball nut’s own flange — internal to the screw assembly, nothing on the machine touches it. The four on the flat, left view, P 40 by C2 24 with C1 8 at each end, is what a sole plate bolts to. They looked irreconcilable until that was clear. The page closes on itself: C1 + C2 + C1 = 8 + 24 + 8 = 40 = L.

Vevor-DSG1605_Spec.jpg

Printed manual supplied with the ball screw kit.

2026-10-09
photograph of a paper page
BF-12 | Vevor | Ball screw support unit, floating end, for a 12 mm shaft. L 20, B 60, H 43, b 30 ±0.02, h 25 ±0.02, B1 35, H1 32.5, E 18, P 46, 4 × ød2 5.5, plus two counterbored holes X 6.6 through, Y 10.8 counterbore, Z 6.5 deep. Bearing 6000ZZ, snapring S10. h = 25 is the screw axis above the mounting face, held to ±0.02 — the same as BK-12, which is what lets the two ends share a plane. L = 20 and B = 60 confirm a measured 20 and 60.08. The part has 4 base holes where Sheet 3a draws 2 for the Z support; the 2 are the counterbored pair, the 4 are the base. | Vevor-BF_Spec.jpg | Printed manual supplied with the ball screw kit. | 2026-10-08 photograph of a paper page
BK-12 | Vevor | Ball screw support unit, fixed end, for a 12 mm shaft. L 25, L1 5, L2 29, L3 5, B 60, H 43, b 30 ±0.02, h 25 ±0.02, B1 35, H1 32.5, E 18, P 46, C1 13, C2 6, C3 5.5, M M4, T 19, with the same two counterbored holes 6.5 / 10.8 / 6.5. Same h = 25 screw axis and same 60 × 43 footprint as BF-12, but 25 thick against BF-12's 20 — the pair are interchangeable in plan and not in depth. | Vevor-BK_Specs.jpg | Printed manual supplied with the ball screw kit, page 7. | 2026-10-08 photograph of a paper page

30-6060

8020 Inc.

T-slotted profile, 30 series, 60 × 60 mm — the gantry beam extrusion, used in stacked pairs. Dimensioned cross-section: 8.14 slot opening, 16.51 slot channel, 2.21 wall, 15.00 slot centrelines, ø6.65 corner bores. The corner bores run lengthwise — reachable only from the ends, which is not obvious from an end-view photograph and rules out every mid-span transverse bolting scheme. The drawing also does not make clear that there is no material behind the centre of each face; that was established on the part. Published properties: Ix = Iy = 36.3307 cm&sup4;, area 9.299 cm², 6063-T6 (not 6105-T5), yield 172.37 N/mm², 0.1441 lb/in. See machine/gantry-beam-joint.md.

8020-30-6060-Profile-Drawing.jpg

8020.net/30-6060.html — product page image carousel.

2026-09-29
screen capture, not the vendor PDF
13025 | 8020 Inc. | T-nut, M8 × 1.25, steel grade 1045, bright zinc — the fastener for both gantry joining plates. Body 16.00 × 16.00, boss 7.80, thickness 6.00. Fits 15 / 30 / 40 Series. No pull-out rating, slip rating or recommended torque is published — the joint capacity is therefore unquantified, and that gap is the vendor's. See machine/gantry-beam-joint.md. | no file — specification transcribed into machine/gantry-beam-joint.md; the letter-dimension drawing was not captured | 8020.net/13025.html | 2026-09-29

## Fetching notes

- Both waveshare.com URLs return HTTP 403 to a plain fetch — curl with no user agent, and most scripted downloaders. They serve normally with a browser User-Agent: curl -L -A "Mozilla/5.0" -o FILE URL
- cdn.amphenol-cs.com is behind a Cloudflare JavaScript challenge — curl and scripted fetches get an HTML challenge page with HTTP 403, not a PDF. Watch for a ~6 KB "PDF": that is the challenge page, not the drawing. Download it in a browser.
- mouser.com blocks automated fetches too ("Access Denied ... automation tools"), and returns that page with HTTP 200 and Content-Type: text/html — so a naive download script saves a ~14 KB "PDF" and reports success. Always check file type or page count after fetching.
- 8020.net is behind a Cloudflare JavaScript challenge — both a plain fetch and one with a browser User-Agent return HTTP 403 with a ~5.6 KB "Just a moment..." page. Same trap as Amphenol above: it is HTML that looks like a successful download. Browser only. The product description on 8020.net/30-6060.html must also be expanded before the drawing and the load/capacity data are visible — they are not in the collapsed page.
- The vendor wiki page for the module is waveshare.com/wiki/ESP32-S3-RS485-CAN (same 403 behaviour); the schematic is linked from its Resources section.
- ams-OSRAM's own product page has moved at least once. The mirror above is stable and is the revision these documents were read against — prefer it over a search result, since figure and table numbers cited in this repo are revision-specific.

## Adding an asset

1. Save the file into this folder.
2. Add a row above: part, vendor, what it is, exact filename, the URL it came from, today's date.
3. Commit only this index.html. The .gitignore here already excludes everything else, so the file itself will not be staged by accident.

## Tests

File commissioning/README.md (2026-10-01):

# Commissioning measurements

**Measured from the machine.** This folder outranks any configuration file - see the standing rule in the
[root README](../README.md).

Nothing has been recorded yet. What needs measuring, and why it matters:

## Travels, per axis

Jog to each hard stop and read the position. Do **not** take these from `$130`/`$131`/`$132`: `$130` read
**889 mm against a real 860 mm** because a catalog preset overwrote the measured value, and the
disagreement went unnoticed while soft-limit protection was quietly absent.

| Axis | Travel | Measured on | Notes |
|---|---|---|---|
| X | | | |
| Y | | | |
| A | | | |
| Z | | | |

## Tape extents, per axis

Needed before cutting magnetic tape, which is one-shot PSA. The tape must span the range the **sensor
bore** sweeps - not the extrusion, not the plate - and the bore may not be centred on its plate, which
shifts the tape's *start* as well as its length.

1. Jog to one hard stop; mark the extrusion at the sensor bore's centreline.
2. Jog to the other stop; mark again.
3. Cut and lay mark-to-mark plus ~10 mm beyond each end.

| Axis | Mark A | Mark B | Tape cut | Laid on |
|---|---|---|---|---|
| X | | | | |
| Y | | | | |
| A | | | | |
| Z | | | | |

Budget: 3 m in stock, three long axes plus Z. **No long run can be recut** - cut the long axes first and
err long rather than short.

## Stiffness and lost motion

📋 **[`stiffness-test.md`](stiffness-test.md)** - the full procedure. Push the spindle nose with a
known force and read six indicator positions, so the deflection can be attributed to a subassembly
rather than lumped into one number.

**It settles the 1/4" vs 3/8" X beam plate choice**, which was decided on the *claim* that the Z
assembly is the largest compliance in the stack. It also gives the gantry's torsional stiffness, which
cannot be computed - 8020 do not publish J - and the lost motion, which matters more than either.

## Squaring and backlash

Y1/Y2 squaring is `Y_AUTO_SQUARE`, so it is set at homing; a loose Y pinion set screw has caused a real
squaring fault before. Record measurements here when taken.

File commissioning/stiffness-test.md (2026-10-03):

# The stiffness test: push the nose, find where it moves

**Not yet run.** This is the procedure for the test that
[`../machine/gantry-beam-joint.md`](../machine/gantry-beam-joint.md) and
[`../machine/loads-and-plate-thicknesses.md`](../machine/loads-and-plate-thicknesses.md) both call
for and neither specifies. Results go in the tables at the bottom and then **outrank every computed
figure in this repo**.

**What it settles:**

- 🔴 **Whether the X beam's joining plates should be 1/4" or 3/8".** That choice was made on the claim
  that the Z assembly is the largest compliance in the stack - **a claim, not a measurement**. The
  plates are bolt-on precisely so the swap stays cheap if this says otherwise.
- **The gantry's torsional stiffness**, which cannot be computed - 8020 publish Ix and Iy for the
  `30-6060` but not J.
- **Lost motion**, which matters more than stiffness and shows up nowhere else.

---

## The one rule that governs everything below

**The indicator stem points along the line of the push.** Stiffness is force divided by deflection
*along the force*. Push fore-aft, read fore-aft. A reading taken at 90° to the load is measuring a
different thing and cannot be divided into the force.

---

## Setup

| | |
|---|---|
| **Force** | **250 N (~56 lbf)**, applied with a luggage or fish scale. **Not 1000 N** - that is 225 lbf, hard to hold steady by hand and enough to unseat a joint or mark a part. Deflection is linear in force, so scale the answer |
| **Pull, don't push** | A spring scale in tension holds a steadier value than a hand |
| **Indicator base** | **A stand on the floor or bench. Never on the machine.** An indicator referenced to the gantry measures a difference, not a displacement |
| **Contact tip** | Ball or radius. On the round spindle body, contact **on its horizontal centreline** - off-centre on a cylinder gives a cosine error and the tip skates under load |
| **Z position** | **Two heights - see below.** Not one, and never at a hard stop |
| **X position** | **Mid-span of the gantry** for the beam numbers. Repeat near one end later if you want the end-plate contribution separated |

### Z height: two positions, and neither resting on a stop

**The whole moving assembly translates**, so the spindle's geometry relative to its own bearing blocks
never changes with Z. What changes is **the vertical distance from the X beam down to the nose**. A
fore-aft force at the nose twists the beam through that arm, so as Z extends the twist contribution
grows while the force-driven bending does not. **Two heights separate those two terms. One height
cannot.**

| | Where | Why not further |
|---|---|---|
| **Low** | ~10 mm **clear** of where the ball nut contacts BF12 | That contact is a **mechanical stop**. Resting on it loads metal-on-metal that is not there in a normal cut, and risks the nut and the support |
| **High** | ~10 mm **clear** of the top stop plate | The top is **protected** - a 6" × 1" × 1/4" plate over the X carriage plate catches the rising block, which is allowed 7 mm of overrun against a **measured** 10 mm to the block's first ball. Back off for the same reason as the bottom: a reading taken against a stop runs through metal-on-metal contact that is not there in a cut |

**If you only do one, do the low one** - it is the worst case and it is where the machine cuts.
Write the Z reading down either way; a deflection without its Z height is not a measurement.

⚠️ **Move indicator 4 with the blocks.** The X carriage plate is 407 mm tall and the Z blocks travel
most of it. If indicator 4 stays at a fixed spot while the blocks move away from it, the (3−4)
difference quietly starts including carriage-plate bending and stops meaning "the Z assembly". Put it
beside wherever the blocks are for that run.

### 🔴 Energise the drives, or the reading is nonsense

With the steppers off, the Y ballscrew back-drives and the whole gantry simply rolls - you would be
measuring the screw, not the structure. **Power the drives so they hold**, and note that motor and
drive compliance is then part of every reading. Mechanically blocking the axis is cleaner if you can
rig it.

### Cycle it, and watch the return to zero

**Load, release, re-zero, repeat. Three cycles. Push both directions.**

⚠️ **Anything that does not come back to zero is LOST MOTION, not stiffness** - and it matters more.
A joint that slips 20 µm and stays slipped shows up in your parts; 20 µm of elastic deflection
largely does not. Record it separately. Do not average it away.

---

## Push 1 - fore-aft (Y). Do this one first.

**The softest path and the one this repo predicts worst.** It loads the X beam about its weak axis
(Iy ~1.71 × 10⁶ against Ix 3.37 × 10⁶ - see the beam file), plus beam torsion through the drop from
the beam down to the nose, plus the entire Z stack.

**Pull the spindle nose horizontally, toward the front of the machine.** Every indicator below reads
**fore-aft**, stem horizontal, pointing along the pull.

| # | Indicator contacts | Stem points | Reading is |
|---|---|---|---|
| **1** | **Spindle body, just below the lower clamp.** On the body's horizontal centreline | fore-aft | **Total** - beam, plates, carriage, Z stack, clamps. ⭐ **The primary number** |
| **2** | **Spindle body, as near the nose as you can reach.** Same centreline, same side as #1 | fore-aft | Pairs with #1 to give **tilt** - see below |
| **3** | **Z plate front face**, beside the lower clamp | fore-aft | Everything below the spindle and clamps |
| **4** | **X carriage plate front face** - exposed above or below the 175 mm Z plate | fore-aft | Everything below the Z assembly |
| **5** | **Beam front face beside the carriage** - the extrusion, or the 46 mm front joining plate | fore-aft | Beam and below |
| **6** | **X end plate, beside a Y bearing block** | fore-aft | Everything but the beam |

### The subtraction - this is the whole point

A single reading on the nose gives a **total**, and a total cannot tell you *where* the compliance
is. Each difference is one subassembly:

| Difference | Is the contribution of |
|---|---|
| 1 − 3 | Spindle body and the two clamps |
| 3 − 4 | **The Z assembly** - rails, blocks, spacers, ball nut |
| 4 − 5 | X carriage plate, X rails and blocks |
| **5 − 6** | 🔴 **The X beam itself. This is the 1/4" vs 3/8" answer** |
| 6 | End plates, Y blocks, Y beams, risers, torsion box |

⚠️ **Approximate, and knowingly so.** Points on different parts rotate as well as translate, so the
differences mix bending and rotation. This is good for finding **which term dominates**, which is the
question being asked. It is not a modal analysis.

### 🔴 Indicators 1 and 2 are the pair that matters most

A nose reading mixes two things that matter very differently:

- the assembly **translating** fore-aft - which is just translation, and
- the spindle **tipping**, because the force acts well below the beam.

**Tipping is what cuts a tapered wall.** A small angle at the clamps becomes a large error at the
tool: **0.001 rad with 50 mm of stickout is 0.05 mm at the cutting edge**, and a single nose reading
would never show it.

**Tilt angle = (reading 1 − reading 2) ÷ (vertical separation between them).** Measure and write down
that separation. Multiply the angle by your working tool stickout to get the error that actually
reaches the part.

---

## Push 2 - vertical (Z)

**This is the torsion measurement**, and torsion is the one number this repo cannot compute. The
spindle sits ~152 mm forward of the beam face, so a vertical force at the nose twists the beam about
its own axis.

**Hang a known weight from the nose** - easier and far more repeatable than pushing upward. All
indicators read **vertical**, stem up or down, contacting a horizontal surface: the nose shoulder,
or the clamp's underside.

| # | Indicator contacts | Reading is |
|---|---|---|
| 1 | Spindle nose shoulder, or collet nut bottom face | Total vertical |
| 2 | Z plate bottom edge | Below the spindle |
| 3 | **Beam front face, top edge** and **beam front face, bottom edge**, beside the carriage | ⭐ **The pair whose difference gives beam twist** |
| 4 | X end plate, at a Y block | Everything but the beam |

**Beam twist = (top reading − bottom reading) ÷ 120 mm**, the section height. That is the number
standing in for the unpublished J.

---

## Push 3 - along the beam (X)

**Lowest priority, skip it unless the first two leave a question.** It loads the X carriage, rails
and ballscrew and barely touches the beam. If the gantry racks in plan, push one end of the beam and
indicate the other instead - that is a different test.

---

## What to avoid

- ❌ **Do not take the primary reading off the collet nut.** It is a threaded part that can shift
  independently of everything you are trying to measure. Use the spindle body.
- ❌ **Do not indicate off a long tool in the collet** for the structural numbers - that adds collet
  and tool compliance, which is real but is not the structure you are deciding about. Worth a
  *separate* reading on a short ground stub if you want the tool-holding contribution.
- ❌ **Do not reference the indicator to any part of the machine.**
- ❌ **Do not average out a failure to return to zero.** Record it as lost motion.

---

## Results

Run the whole of Push 1 twice, once at each Z height, and fill in a copy of the table for each.

**Push 1 - fore-aft, 250 N, X at mid-span. Z at ______ mm (circle: LOW / HIGH). Date: ______**

| # | Position | Out (µm) | Back (µm) | Residual (µm) |
|---|---|---|---|---|
| 1 | Spindle body below lower clamp | | | |
| 2 | Spindle body near nose | | | |
| 3 | Z plate front face | | | |
| 4 | X carriage plate front face | | | |
| 5 | Beam front face by carriage | | | |
| 6 | End plate at Y block | | | |

Vertical separation between indicators 1 and 2: ______ mm → tilt ______ rad
→ at ______ mm stickout, tool-tip error ______ mm

| Subassembly | Contribution (µm) | % of total |
|---|---|---|
| Spindle and clamps (1−3) | | |
| Z assembly (3−4) | | |
| X carriage and rails (4−5) | | |
| **X beam (5−6)** | | |
| Everything below the beam (6) | | |

**Push 2 - vertical, ______ N hung at the nose. Date: ______**

| # | Position | Out (µm) | Back (µm) | Residual (µm) |
|---|---|---|---|---|
| 1 | Nose shoulder | | | |
| 2 | Z plate bottom edge | | | |
| 3a | Beam front, top edge | | | |
| 3b | Beam front, bottom edge | | | |
| 4 | End plate at Y block | | | |

Beam twist = (3a − 3b) ÷ 120 mm = ______ rad

---

## Then what

| If the X beam term (5−6) is… | Then |
|---|---|
| **a small share of the total** | The 1/4" plate choice was right. Record it and stop - the claim it rested on is now measured |
| **comparable to the Z assembly** | 3/8" is worth the ~3 lb. The plates are bolt-on for exactly this |
| **dominant** | Something is wrong with the joint, not the plate thickness. Check the T-nut preload before buying anything |

⚠️ **Whatever this test says, go back and correct the computed figures in
[`../machine/gantry-beam-joint.md`](../machine/gantry-beam-joint.md).** They are estimates with a
crude beam model behind them, and a note that contradicts its own correction is worse than no note.

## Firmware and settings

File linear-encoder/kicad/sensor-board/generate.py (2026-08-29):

# -*- coding: utf-8 -*-
"""Generate sensor-board.kicad_sch (KiCad 10) for the CNCBuild AS5311 sensor board.

One of these sits in each puck: AS5311 on the tape-facing side, RJ45 jack and passives on
the other. The cable pinout is NOT a free choice here - it must mirror the controller board
exactly (see ../controller-board/netlist.txt), because it is the same CAT5 run:

    1 = A    2 = GND   3 = B      4 = +3V3
    5 = GND  6 = GND   7 = MagDECn   8 = GND

Same drawing convention as the controller board: connections are made by NET LABEL on a
short wire stub at each pin, not by point-to-point wires. Electrically identical for
netlist/ERC purposes and far less error-prone to generate.
"""
import uuid, io, os

OUT = os.path.dirname(os.path.abspath(__file__))
U = lambda: str(uuid.uuid4())


def f(v):
    return str(int(v)) if float(v) == int(v) else ("%.4f" % v).rstrip('0').rstrip('.')


# --------------------------------------------------------------- symbol geometry
# KiCad convention: a pin's `at` IS its connection point, and `rot` points FROM that
# point TOWARD the body. Symbol space is Y-up; the sheet is Y-down, so py is mirrored
# when the symbol is placed.
COL_Y = [11.43, 8.89, 6.35, 3.81, 1.27, -1.27, -3.81, -6.35, -8.89, -11.43]
RJ_Y = [8.89, 6.35, 3.81, 1.27, -1.27, -3.81, -6.35, -8.89]
TVS_Y = [5.08, 2.54, 0, -2.54]
FONT = '(effects (font (size 1.27 1.27)))'

# AS5311, TSSOP-20. DIP numbering runs counterclockwise: 1..10 down the left side,
# 11..20 up the right. Names come from the datasheet Table 1 (rev 1.12, p.4).
AS_NAMES = {1: "NC", 2: "MagINCn", 3: "MagDECn", 4: "A", 5: "B", 6: "NC", 7: "Index",
            8: "VSS", 9: "Prog", 10: "NC", 11: "NC", 12: "DO", 13: "CLK", 14: "CSn",
            15: "PWM", 16: "NC", 17: "NC", 18: "VDD3V3", 19: "VDD5V", 20: "NC"}


def as5311_pins():
    out = []
    for i, y in enumerate(COL_Y):                 # 1..10 down the left
        out.append((str(i + 1), -7.62, y, 0))
    for i, y in enumerate(reversed(COL_Y)):       # 11..20 up the right
        out.append((str(i + 11), 7.62, y, 180))
    return out


def rj_pins():
    # Plastic, UNSHIELDED jack: no shield tab, so no SH pin. That is the whole point -
    # with nothing to bond to, the cable screen floats at this end by construction.
    return [(str(i + 1), -7.62, y, 0) for i, y in enumerate(RJ_Y)]


def tvs_pins():
    out = [(str(i + 1), -6.35, y, 0) for i, y in enumerate(TVS_Y)]
    out.append(("5", 0, -7.62, 90))
    return out


RC_PINS = [("1", 0, 3.81, 270), ("2", 0, -3.81, 90)]
TP_PINS = [("1", 0, -3.81, 90)]


def lib_symbol(name, bodyrect, pins, ref, val, hide_names=False, names=None):
    x0, y0, x1, y1 = bodyrect
    s = []
    s.append('  (symbol "%s" (pin_names (offset 0.254)%s) (exclude_from_sim no) (in_bom yes) (on_board yes)'
             % (name, ' hide' if hide_names else ''))
    s.append('    (property "Reference" "%s" (at 0 %s 0) %s)' % (ref, f(y1 + 2.54), FONT))
    s.append('    (property "Value" "%s" (at 0 %s 0) %s)' % (val, f(y0 - 2.54), FONT))
    s.append('    (property "Footprint" "" (at 0 0 0) (effects (font (size 1.27 1.27)) hide))')
    s.append('    (property "Datasheet" "~" (at 0 0 0) (effects (font (size 1.27 1.27)) hide))')
    s.append('    (symbol "%s_0_1"' % name.split(":")[-1])
    s.append('      (rectangle (start %s %s) (end %s %s) (stroke (width 0.254) (type default)) (fill (type background)))'
             % (f(x0), f(y0), f(x1), f(y1)))
    s.append('    )')
    s.append('    (symbol "%s_1_1"' % name.split(":")[-1])
    for num, px, py, rot in pins:
        pname = (names or {}).get(int(num) if num.isdigit() else num, num)
        s.append('      (pin passive line (at %s %s %d) (length 2.54) (name "%s" %s) (number "%s" %s))'
                 % (f(px), f(py), rot, pname, FONT, num, FONT))
    s.append('    )')
    s.append('  )')
    return "\n".join(s)


LIBS = [
    lib_symbol("cnc:AS5311", (-5.08, -12.7, 5.08, 12.7), as5311_pins(), "U", "AS5311", names=AS_NAMES),
    lib_symbol("cnc:RJ45_8_UNSHLD", (-5.08, -10.16, 5.08, 10.16), rj_pins(), "J", "RJ45_unshielded_no_magnetics"),
    lib_symbol("cnc:TVS_4", (-3.81, -7.62, 3.81, 7.62), tvs_pins(), "D", "TVS_array_4ch"),
    lib_symbol("cnc:R", (-1.016, -2.54, 1.016, 2.54), RC_PINS, "R", "R", hide_names=True),
    lib_symbol("cnc:C", (-1.016, -2.54, 1.016, 2.54), RC_PINS, "C", "C", hide_names=True),
    lib_symbol("cnc:TP", (-1.016, -1.016, 1.016, 1.016), TP_PINS, "TP", "TestPoint", hide_names=True),
]
SYM_PINS = {"cnc:AS5311": as5311_pins(), "cnc:RJ45_8_UNSHLD": rj_pins(), "cnc:TVS_4": tvs_pins(),
            "cnc:R": RC_PINS, "cnc:C": RC_PINS, "cnc:TP": TP_PINS}

SHEET_UUID = U()
body, wires, labels, noconns = [], [], [], []

GRID = 1.27


def snap(v):
    """Placement origins must land on the 1.27 mm connection grid. Every pin offset and stub
    length in this file is already a multiple of 1.27, so snapping the origin puts every
    endpoint on-grid. KiCad flags off-grid endpoints because they can silently fail to
    connect once the sheet is edited by hand."""
    return round(v / GRID) * GRID
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

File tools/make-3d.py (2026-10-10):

#!/usr/bin/env python3
"""Generate machine/drawings/model-3d.html from the dimension registry.

Every box in the model is placed from registry values, not from numbers typed
here. That is the whole point: if a dimension moves and a part stops fitting,
the model shows it as a visible gap or overlap rather than hiding it. Re-run
this after any registry change.

    python tools/make-3d.py

Where a placement could NOT be derived, it is listed in ASSUMPTIONS below and
printed on the page itself, so nobody mistakes a guess for a dimension.
"""
from __future__ import annotations

import json
import sys
from pathlib import Path

sys.path.insert(0, str(Path(__file__).resolve().parent))
from dims import Registry  # noqa: E402

ROOT = Path(__file__).resolve().parent.parent
OUT = ROOT / "machine" / "drawings" / "model-3d.html"
VENDOR = ROOT / "machine" / "drawings" / "vendor" / "three.min.js"

# ---------------------------------------------------------------- the frame
#
#   X  across the machine, 0 at the rear plate's LEFT end  (= outer left face)
#   Y  fore-aft,           0 at the torsion box's BACK edge, +Y forward
#   Z  up,                 0 at the torsion box's TOP SKIN
#
# Three.js is Y-up, so the writer swaps: three(x, z, y).

ASSUMPTIONS = [
    "Y HOME is taken as the X end plate's BACK edge level with the Y beam's back "
    "end, mirroring the documented Y MAX (front face level with the beam end). "
    "The rear hard stop is not dimensioned anywhere.",
    "X HOME is the carriage plate butted against the left end plate's inner face. "
    "No stop or soft-limit figure exists for it.",
    "Z AT MAX puts the butted block pair at the top of the 400 mm rail, and the Z "
    "plate is centred on that pair. The plate's exact offset along the spacers is "
    "not dimensioned.",
    "The front fin's taper is drawn with a VERTICAL FRONT EDGE and the 200-to-100 "
    "taper on its back. Sheet 1 gives the widths, not which edge is square.",
    "The box tongue is drawn from the bottom skin's top face up, 179 tall, to land "
    "at the 60 proud the registry gives. torsion-box.md says 180.",
    "THE BALL NUTS ARE DRAWN AT MID TRAVEL. None of the three axes has a home or "
    "park position in the registry, so the nut is put halfway along its screw. Where a "
    "nut sits is therefore the one thing in the drive train NOT to read off this model.",
    "THE CASTINGS' RAILS ARE DRAWN SOLID. The real casting is open between the two "
    "rails that join its screw end to its motor plate. Solid is the conservative way "
    "round for an interference check - a clearance the model SHOWS is real, one it "
    "denies may not be.",
    "EACH CASTING IS PLACED BY ITS SCREW. Its bearing end is set where the screw's long "
    "journal ends and the rest follows forward, so the motor's position is a consequence "
    "of the 1000 screw rather than a figure anyone chose. If a casting bolts somewhere "
    "specific along its beam, that is not captured.",
    "NO BASE OR LEGS - deliberately out of scope. The box sits on the ground plane.",
]


def main() -> int:
    reg = Registry()
    reg.evaluate_all()
    if reg.errors:
        print("registry does not evaluate; fix that first", file=sys.stderr)
        return 2
    v = {s: reg.value(s) for s in reg.order}

    P = []  # parts: name, group, colour, [x0,y0,z0], [x1,y1,z1]

    def box(name, group, colour, x0, y0, z0, x1, y1, z1):
        P.append({"n": name, "g": group, "c": colour, "t": "box",
                  "p": [min(x0, x1), min(y0, y1), min(z0, z1)],
                  "q": [max(x0, x1), max(y0, y1), max(z0, z1)]})

    def cyl(name, group, colour, cx, cy, z0, z1, r, axis="z", seg=36):
        """A cylinder along one axis. The spindle is round and a box misrepresents
        its clearance - at 45 degrees a box corner sticks out r*(sqrt2-1) further.
        Bolt heads are round for the same reason and are drawn with few segments.

        cx, cy are the two coordinates the axis does NOT run along, in machine
        order: for axis 'z' that is (x, y), for 'x' it is (y, z), for 'y' (x, z).
        """
        lo, hi = min(z0, z1), max(z0, z1)
        if axis == "z":
            p, q = [cx - r, cy - r, lo], [cx + r, cy + r, hi]
        elif axis == "x":
            p, q = [lo, cx - r, cy - r], [hi, cx + r, cy + r]
        else:
            p, q = [cx - r, lo, cy - r], [cx + r, hi, cy + r]
        P.append({"n": name, "g": group, "c": colour, "t": "cyl", "ax": axis,
                  "cx": cx, "cy": cy, "r": r, "z0": lo, "z1": hi, "seg": seg,
                  "p": p, "q": q})

    def prism(name, group, colour, profile, ya, yb, holes=None):
        """An X-Z profile extruded along fore-aft. The fins are not boxes.

        p/q stay the bounding box so the camera framing and the interference
        check keep working; the check is then CONSERVATIVE on a prism, which is
        the safe direction - it may flag a touch that the real taper clears.
        """
        xs = [pt[0] for pt in profile]
        zs = [pt[1] for pt in profile]
        P.append({"n": name, "g": group, "c": colour, "t": "prism",
                  "profile": profile, "holes": holes or [],
                  "ya": min(ya, yb), "yb": max(ya, yb),
                  "p": [min(xs), min(ya, yb), min(zs)],
                  "q": [max(xs), max(ya, yb), max(zs)]})

    W = v["REAR_PLATE_L"]            # 1211.75, the machine's outer width
    D = v["BOX_FORE_AFT"]            # 1156.35
    TT = v["T_BOX_TONGUE"]           # 19
    SKIN = v["T_BB_SKIN"]            # 19

    # ---- torsion box -----------------------------------------------------
    box("Torsion box", "box", 0xC9A227, 0, 0, -v["BOX_THK"], W, D, 0)
    tz0, tz1 = -(v["BOX_THK"] - SKIN), v["BOX_TONGUE_PROUD"]
    box("Back tongue", "box", 0xA07B16, -TT, -TT, tz0, W + TT, 0, tz1)
    for x0 in (-TT, W):
        box("Side tongue", "box", 0xA07B16,
            x0, v["SIDE_TONGUE_START"], tz0, x0 + TT, v["SIDE_TONGUE_END"], tz1)

    # ---- the plates that stand on the skin -------------------------------
    box("Rear plate", "plates", 0x8899AA, 0, 0, 0, W, v["T_REAR_PLATE"], v["REAR_PLATE_W"])

    sp = v["T_SIDE_PLATE"]
    y0, y1 = v["SIDE_TONGUE_START"], v["SIDE_TONGUE_END"]
    for x0 in (0.0, W - sp):
        box("Side plate", "plates", 0x8899AA, x0, y0, 0, x0 + sp, y1, v["SIDE_PLATE_H"])

    # ---- Y beams ---------------------------------------------------------
    # The beam's height comes from the FIN, not the side plate: the window's top
    # edge is the beam's underside. 182 + 120 lands on FIN_STOCK's measured 302,
    # which is the cross-check that this chain closes.
    ybot = v["Y_BEAM_UNDERSIDE"]
    ytop = ybot + v["BEAM_H"]
    lx0, rx0 = v["Y1_EXT_FACE_X"], v["Y2_EXT_FACE_X"] - v["EXT_W"]
    for x0 in (lx0, rx0):
        box("Y beam", "ybeams", 0x4A7DB5, x0, y0, ybot, x0 + v["EXT_W"], y1, ytop)

    # ---- front fins ------------------------------------------------------
    # They CAP THE Y BEAM'S FRONT END - plane normal to fore-aft, like the rear
    # plate does at the back - and the taper faces INBOARD, so the outboard edge
    # is square. Corrected 2026-10-03; the first model had them on the beams'
    # sides, which is the wrong plane entirely.
    fb, ft, h = v["FIN_BASE_W"], v["FIN_TOP_W"], v["FIN_STOCK"]
    wo, ww = v["WINDOW_OUTB_DRAWN"], v["WINDOW_W"]
    wz0, wz1 = v["WINDOW_Z_LOW"], v["WINDOW_Z_LOW"] + v["WINDOW_H"]
    for outer, sgn in ((0 - v["FIN_PROUD"], +1), (W + v["FIN_PROUD"], -1)):
        # The window's outboard edge lands on the Y beam's OUTER FACE - 3.175 and
        # 1208.575 - which is what Sheet 1 says it is aligned to, and the check
        # that WINDOW_OUTB_DRAWN's 20 is right where the measured 19 is not.
        wa, wb = outer + sgn * wo, outer + sgn * (wo + ww)
        prism("Front fin", "plates", 0x6FA8DC,
              [[outer, 0], [outer + sgn * fb, 0],
               [outer + sgn * ft, h], [outer, h]],
              y1, y1 + v["T_FIN"],
              holes=[[[wa, wz0], [wb, wz0], [wb, wz1], [wa, wz1]]])

    # ---- the interposer, under each beam and out through the window -------
    ip_t = v["T_INTERPOSER"]
    ip_front = y1 + v["T_FIN"] + v["INTERPOSER_PROUD"]
    for x0 in (lx0, rx0):
        box("Interposer", "ybeams", 0xC0652A, x0, ip_front - v["INTERPOSER_L"],
            ybot - ip_t, x0 + v["INTERPOSER_W"], ip_front, ybot)

    # ---- X gantry, at Y home ---------------------------------------------
    xep_t = v["T_X_ENDPLATE"]
    xb_x0 = lx0 + v["EXT_W"] + v["RAIL_STACK"] + xep_t
    xb_x1 = xb_x0 + v["BEAM_LEN"]
    xep_back = y0                       # ASSUMPTION: Y home
    xep_front = xep_back + v["XEP_W"]
    xb_top = ytop + v["XEP_TOP_ABOVE_BEAM"]
    xb_bot = xb_top - v["BEAM_H"]
    box("X beam", "gantry", 0x4A7DB5, xb_x0, xep_back, xb_bot,
        xb_x1, xep_back + v["EXT_W"], xb_top)
    for x0 in (xb_x0 - xep_t, xb_x1):
        box("X end plate", "gantry", 0x6FA8DC,
            x0, xep_back, xb_top - v["XEP_H"], x0 + xep_t, xep_front, xb_top)
        box("Y nut doubler", "gantry", 0xB06000,
            x0 - v["T_DOUBLER"] if x0 < xb_x0 else x0 + xep_t, xep_back,
            xb_top - v["XEP_H"],
            x0 if x0 < xb_x0 else x0 + xep_t + v["T_DOUBLER"],
            xep_back + v["DOUBLER_H"], xb_top - v["XEP_H"] + v["DOUBLER_H"])

    # ---- X carriage, at X home -------------------------------------------
    # The X rails sit RAIL_LOW_Z up the beam's front face; Sheet 3 puts the lower
    # block row's centre 46 up the carriage plate, so the plate's bottom follows.
    xbeam_front = xep_back + v["EXT_W"]
    cp_bot = xb_bot + v["RAIL_LOW_Z"] - 46.0
    # X HOME IS THE OPERATOR'S LEFT, which is MAX X in this frame, not min.
    # X 0 is the rear plate's left as seen FROM BEHIND - the operator, standing at
    # the front, has it on their right. The first model put the carriage at min X
    # and so parked it back-RIGHT.
    cp_x1 = xb_x1
    cp_x0 = cp_x1 - v["XEP_W"]
    # The plate bolts to the BLOCKS, so it stands RAIL_STACK off the beam's face -
    # not on it. Caught by the interference check on 2026-10-03, which had the X
    # rail passing straight through the plate; everything on the Z axis moved
    # forward 30 with it.
    cp_back = xbeam_front + v["RAIL_STACK"]
    box("X carriage plate", "z", 0xD98E04, cp_x0, cp_back, cp_bot,
        cp_x1, cp_back + v["T_X_CARRIAGE_PLATE"], cp_bot + 407.0)

    # ---- Z plate and spindle, at Z max -----------------------------------
    cp_front = cp_back + v["T_X_CARRIAGE_PLATE"]
    rail_top = cp_bot + 407.0 - 7.0
    block_mid = rail_top - (v["BLOCK_BUTTED"] / 2)       # ASSUMPTION: Z at max
    zp_back = cp_front + v["RAIL_STACK"] + v["SPACER_T"]
    zp_cx = (cp_x0 + cp_x1) / 2
    box("Z plate", "z", 0xD98E04,
        zp_cx - v["Z_PLATE_W"] / 2, zp_back, block_mid - v["Z_PLATE_L"] / 2,
        zp_cx + v["Z_PLATE_W"] / 2, zp_back + v["T_Z_PLATE"],
        block_mid + v["Z_PLATE_L"] / 2)

    # The spindle axis is CLAMP_BORE_OFFSET off the Z plate's FRONT face - that
    # term is what makes SPINDLE_OFFSET add up from the carriage plate.
    zp_front = zp_back + v["T_Z_PLATE"]
    sp_axis = zp_front + v["CLAMP_BORE_OFFSET"]
    r = v["SPINDLE_D"] / 2
    bar_bot = block_mid - v["SPINDLE_BARREL_L"] / 2
    cyl("Spindle barrel", "z", 0x9AA3AB, zp_cx, sp_axis,
        bar_bot, bar_bot + v["SPINDLE_BARREL_L"], r)
    cyl("Collet nut", "z", 0x2E2E2E, zp_cx, sp_axis,
        bar_bot - v["SPINDLE_COLLET_END"], bar_bot - v["SPINDLE_SHOULDER_DROP"],
        v["SPINDLE_NUT_D"] / 2)

    # Two clamps, CLAMP_CENTRES apart about the Z plate's mid-height, each
    # CLAMP_AXIAL tall and CLAMP_W across, reaching from the plate's face past
    # the bore so the barrel passes through them.
    for cz in (block_mid - v["CLAMP_CENTRES"] / 2, block_mid + v["CLAMP_CENTRES"] / 2):
        box("Spindle clamp", "z", 0x5E6B75,
            zp_cx - v["CLAMP_W"] / 2, zp_front, cz - v["CLAMP_AXIAL"] / 2,
            zp_cx + v["CLAMP_W"] / 2, sp_axis + r + 8, cz + v["CLAMP_AXIAL"] / 2)

    # ---- ball screws, nuts, BF12 and the stepper castings -----------------
    # Four identical 1605 screws, each running from a BF12 at one end to a cast
    # stepper frame at the other, carrying a nut that something bolts to.
    #
    # Neither support is a block. Both are a tall centre boss holding the
    # bearing with a LOWER WING either side, and the mounting bolts go through
    # the wings - so each is drawn as two parts. One box would put a 43 boss
    # across the full 60 width and show the tongue fouling metal that is not
    # there.
    SCR, JRN = v["SCREW_D"] / 2, v["SCREW_JOURNAL_D"] / 2
    JB, JC = v["SCREW_JOURNAL_BF"], v["SCREW_JOURNAL_CAST"]
    STEEL, DARK, SUP = 0xB9C0C7, 0x8A9097, 0x7E6B8F
    NUTC, MOT = 0xC06000, 0x3C4248

    def screw(axis, c0, c1, lo, oal, bf_low):
        """lo to lo+oal along `axis`. The journals are drawn at their real 10,
        which is what makes the length visibly land inside its two supports."""
        a, b = (JB, JC) if bf_low else (JC, JB)
        cyl("Screw journal", "drive", DARK, c0, c1, lo, lo + a, JRN, axis)
        cyl("Ball screw", "drive", STEEL, c0, c1, lo + a, lo + oal - b, SCR, axis)
        cyl("Screw journal", "drive", DARK, c0, c1, lo + oal - b, lo + oal, JRN, axis)

    def span(axis, along0, along1, c0lo, c0hi, c1lo, c1hi):
        """A box given as (along the screw) x (the other two), in machine order."""
        if axis == "y":
            return (c0lo, along0, c1lo, c0hi, along1, c1hi)
        if axis == "x":
            return (along0, c0lo, c1lo, along1, c0hi, c1hi)
        return (c0lo, c1lo, along0, c0hi, c1hi, along1)

    def support(kind, axis, c0, c1, inner, grow, seat, up):
        """BF12 or the casting's screw end, as wing + boss.

        inner is the face the screw enters, grow is +1/-1 along the screw, and
        up is +1/-1 for which way the part stands off its seating plane.
        """
        if kind == "bf12":
            depth, w, bw = v["T_BF12_BLOCK"], v["BF12_W"], v["BF12_BOSS_W"]
            wh, bh = v["BF12_WING_H"], v["BF12_H"]
        else:
            depth, w, bw = v["BK12_L"], v["CASTING_FOOTPRINT_W"], v["CASTING_BOSS_W"]
            wh, bh = v["CASTING_WING_H"], v["CASTING_BOSS_H"]
        a0, a1 = sorted((inner, inner + grow * depth))
        for name, half, h in (("wing", w / 2, wh), ("boss", bw / 2, bh)):
            s0, s1 = sorted((seat, seat + up * h))
            lbl = ("BF12 " if kind == "bf12" else "Casting ") + name
            box(lbl, "drive", SUP, *span(axis, a0, a1, c0 - half, c0 + half, s0, s1))

    def nut(axis, c0, c1, mid, face_dir):
        """The ball nut, its bolting face NUT_AXIS_TO_FACE off the axis."""
        h = v["NUT_AXIS_TO_FACE"]
        a0, a1 = mid - v["NUT_OAL"] / 2, mid + v["NUT_OAL"] / 2
        box("Ball nut", "drive", NUTC,
            *span(axis, a0, a1, c0 - v["NUT_W"] / 2, c0 + v["NUT_W"] / 2,
                  c1 - h, c1 + h))
        # the bolting face, drawn thin so it is obvious which side bolts
        f = c1 + face_dir * h
        box("Nut bolt face", "drive", 0xE08A2E,
            *span(axis, a0, a1, c0 - v["NUT_FACE_X"] / 2, c0 + v["NUT_FACE_X"] / 2,
                  min(f, f - face_dir * 2), max(f, f - face_dir * 2)))

    def rails(axis, c0, c1, start, grow):
        """The open rails joining the casting's screw end to its motor plate.

        Drawn SOLID, which is conservative: the real casting is open between
        them. A clearance the model shows is therefore real; one it denies may
        not be.
        """
        n = v["CASTING_FOOTPRINT_L"] - v["BK12_L"]
        a0, a1 = sorted((start, start + grow * n))
        h, w = v["CASTING_RAIL_H"] / 2, v["CASTING_FOOTPRINT_W"] / 2
        box("Casting rails", "drive", SUP,
            *span(axis, a0, a1, c0 - w, c0 + w, c1 - h, c1 + h))

    def motor(axis, c0, c1, plate_at, grow):
        """The casting's motor plate and the NEMA 23 hanging off it."""
        t, fw = v["MOTOR_FRAME_T"], v["MOTOR_FRAME_W"] / 2
        bl, bs = v["MOTOR_BODY_L"], v["MOTOR_BODY_SQ"] / 2
        p0, p1 = sorted((plate_at, plate_at + grow * t))
        box("Motor plate", "drive", SUP,
            *span(axis, p0, p1, c0 - fw, c0 + fw, c1 - fw, c1 + fw))
        m0, m1 = sorted((plate_at + grow * t, plate_at + grow * (t + bl)))
        box("Stepper motor", "drive", MOT,
            *span(axis, m0, m1, c0 - bs, c0 + bs, c1 - bs, c1 + bs))

    # ------------------------------------------------ Y1 and Y2
    y_axis_z = ybot - v["Y_SCREW_BELOW_BEAM"]
    y_seat_z = ybot - ip_t                      # the interposer's underside
    y_lo = v["T_REAR_PLATE"]                    # BF12 seats on the rear plate
    y_hi = y_lo + v["SCREW_OAL_LONG"]
    for x0 in (lx0, rx0):
        cx = x0 + v["EXT_W"] / 2
        screw("y", cx, y_axis_z, y_lo, v["SCREW_OAL_LONG"], bf_low=True)
        support("bf12", "y", cx, y_axis_z, y_lo, +1, y_seat_z, -1)
        # ASSUMPTION: the nut is drawn at mid travel - it has no home position
        nut("y", cx, y_axis_z, (y_lo + y_hi) / 2, -1)
        cast_in = y_hi - v["BK12_L"]
        support("casting", "y", cx, y_axis_z, cast_in, +1, y_seat_z, -1)
        rails("y", cx, y_axis_z, cast_in + v["BK12_L"], +1)
        motor("y", cx, y_axis_z, cast_in + v["CASTING_FOOTPRINT_L"], +1)

    # ------------------------------------------------ X, on TOP of its beam
    x_seat_z = xb_top + ip_t
    x_axis_z = x_seat_z + v["SCREW_AXIS_H"]
    x_axis_y = xep_back + v["EXT_W"] / 2
    x_hi = xb_x1                                # BF12 on the right plate's tongue
    x_lo = x_hi - v["SCREW_OAL_LONG"]
    screw("x", x_axis_y, x_axis_z, x_lo, v["SCREW_OAL_LONG"], bf_low=False)
    support("bf12", "x", x_axis_y, x_axis_z, x_hi, -1, x_seat_z, +1)
    nut("x", x_axis_y, x_axis_z, (x_lo + x_hi) / 2, +1)
    support("casting", "x", x_axis_y, x_axis_z, x_lo + v["BK12_L"], -1, x_seat_z, +1)
    rails("x", x_axis_y, x_axis_z, x_lo, -1)
    motor("x", x_axis_y, x_axis_z, x_lo + v["BK12_L"] - v["CASTING_FOOTPRINT_L"], -1)

    # ------------------------------------------------ Z, up the carriage plate
    # No interposer here, which is why the Z nut face sits 45 off the plate
    # where the beams get 55.
    z_axis_y = cp_front + v["SCREW_AXIS_H"]
    z_lo = cp_bot
    z_hi = z_lo + v["SCREW_OAL_Z"]
    screw("z", zp_cx, z_axis_y, z_lo, v["SCREW_OAL_Z"], bf_low=True)
    support("bf12", "z", zp_cx, z_axis_y, z_lo, +1, cp_front, +1)
    nut("z", zp_cx, z_axis_y, (z_lo + z_hi) / 2, +1)
    z_cast_in = z_hi - v["BK12_L"]
    support("casting", "z", zp_cx, z_axis_y, z_cast_in, +1, cp_front, +1)
    rails("z", zp_cx, z_axis_y, z_cast_in + v["BK12_L"], +1)
    motor("z", zp_cx, z_axis_y, z_cast_in + v["CASTING_FOOTPRINT_L"], +1)

    # ---- linear rails and bearing blocks ---------------------------------
    # Rails sit on their beam's face at RAIL_LOW_Z / RAIL_HIGH_Z; the block
    # envelopes the rail and stands RAIL_STACK off the face, which is the
    # measured figure the whole machine's offsets are built on.
    rw, st, bw, bl = v["RAIL_W"], v["RAIL_STACK"], v["BLOCK_W"], v["BLOCK_BUTTED"]
    RC, BC = 0x7E8C99, 0xE04F3D

    def rail_and_blocks(axis, face, d, zc, along, bfrom, bto):
        """axis: which coordinate the stack grows along; d: +1 / -1."""
        for z in zc:
            if axis == "x":
                box(f"{along} rail", "motion", RC, face, bfrom[0], z - rw / 2,
                    face + d * rw, bto[0], z + rw / 2)
                box(f"{along} block", "motion", BC, face, bfrom[1], z - bw / 2,
                    face + d * st, bto[1], z + bw / 2)
            else:                                   # stack grows along fore-aft
                box(f"{along} rail", "motion", RC, bfrom[0], face, z - rw / 2,
                    bto[0], face + d * rw, z + rw / 2)
                box(f"{along} block", "motion", BC, bfrom[1], face, z - bw / 2,
                    bto[1], face + d * st, z + bw / 2)

    # Y: on each beam's INNER face, blocks carried by the X end plate
    gb = (xep_back, xep_back + bl)
    rail_and_blocks("x", lx0 + v["EXT_W"], +1, [ybot + v["RAIL_LOW_Z"], ybot + v["RAIL_HIGH_Z"]],
                    "Y", (y0, gb[0]), (y1, gb[1]))
    rail_and_blocks("x", rx0, -1, [ybot + v["RAIL_LOW_Z"], ybot + v["RAIL_HIGH_Z"]],
                    "Y", (y0, gb[0]), (y1, gb[1]))
    # X: on the X beam's FRONT face, blocks carried by the carriage plate
    # The butted pair is BLOCK_BUTTED = 154.18 against a 154 plate, so it is
    # CENTRED on the plate and the 0.09 that hangs over each end is end cap.
    bo = (bl - v["XEP_W"]) / 2
    rail_and_blocks("y", xbeam_front, +1, [xb_bot + v["RAIL_LOW_Z"], xb_bot + v["RAIL_HIGH_Z"]],
                    "X", (xb_x0, cp_x0 - bo), (xb_x1, cp_x1 + bo))
    # Z: vertical, on the carriage plate's front face
    for xc in (zp_cx - v["Z_RAIL_COL"], zp_cx + v["Z_RAIL_COL"]):
        box("Z rail", "motion", RC, xc - rw / 2, cp_front, cp_bot + 7,
            xc + rw / 2, cp_front + rw, cp_bot + 7 + v["Z_RAIL_L"])
        box("Z block", "motion", BC, xc - bw / 2, cp_front, block_mid - bl / 2,
            xc + bw / 2, cp_front + st, block_mid + bl / 2)
        # The spacer bar is SANDWICHED between the blocks and the Z plate - one per
        # rail, each spanning that rail's two blocks. The model had the gap but
        # nothing in it until he spotted the omission, 2026-10-03.
        box("Z spacer", "z", 0xBFC7CE,
            xc - v["SPACER_W"] / 2, cp_front + st, block_mid - v["SPACER_L"] / 2,
            xc + v["SPACER_W"] / 2, cp_front + st + v["SPACER_T"],
            block_mid + v["SPACER_L"] / 2)
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

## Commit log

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2026-08-26 The schematic is verified now, not merely written
    KiCad 10.0.5 installed, so the previous commit's "nobody has opened it" caveat is
    discharged with evidence rather than removed:
    - kicad-cli sch erc and sch export netlist both load the file.
    - KiCad's OWN extracted netlist matches netlist.txt exactly - all 15 nets, zero
    mismatches, no extra or missing nodes. That is the check that matters: it proves
    the net labels actually attached to the pins rather than merely sitting near them.
    ERC went 134 -> 22. The 112 fixed were real:
    - 107 endpoint_off_grid. Placement origins were not multiples of 1.27mm, so every
    pin and stub sat off the connection grid. Connections resolved anyw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
    [controller-board.kicad_sch]
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2026-08-29 Where the 3V3 actually comes from, and the cap that is missing
    The board makes no power - 3V3 arrives on P1 pin 1 and fans straight out to four
    jacks and four pull-ups. The line this replaces said the load was "on a rail rated
    far above it", which is true but unfalsifiable, so here is the chain from the
    Waveshare schematic that has been sitting in manufacturer-assets all along:
    MP1605GTF-Z buck off 5V, 0.6*(1+200/44.2) = 3.314V, rated 2A. Four sensors at 21mA
    max plus the pull-ups is ~90mA, about 4% of it. Cable drop is ~9mV. None of it is
    close.
    The constraint is upstream of the module rather than on this board: size whatever
    feeds its 5V for the module PLUS 90mA.
    Opened as item 0: this b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
    [sensor-board.kicad_sch]
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2026-10-02 Dimension registry, authoritative for values, with a Fusion export
    dimensions/registry.toml holds 66 symbols - primitives with provenance, derived values
    as expressions. tools/dims.py evaluates them (ast walk, not eval - a data file should
    not execute), checks for cycles and undefined refs, and exports.
    The feature that justifies it is 'deps': change a primitive and it lists every value
    that must be re-derived. Today's two orphaned derivations - the shelf bolt keyed off a
    beam face that moved, and the 1.8 proud figure keyed off a column corrected from 20 to
    35 - would both have been caught by it. A symbol alone would not have.
    Verified by reproducing 16 prose numbers independently from the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
    [fusion-parameters.csv]
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2026-10-02 Shelf bar to 60 mm - exactly the beam's footprint
    The 3in existed to reach back under the back joining plate. With the beam flush its
    back face IS the plate's back edge, so the joining plate sits behind the plate in air
    and there is nothing to reach.
    Shortening deletes a hazard rather than trimming a part: the file warned the joining
    plate must not hang proud because 'the bar passes under where that plate lands'. End
    the bar at Y 0 and it never passes under it - the failure mode goes by construction
    instead of by care at assembly.
    In the registry SHELF_BAR_L is now an expression on EXT_W rather than a literal, so it
    cannot drift from the beam it is sized to.
    Flagged: check the real counte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
    [fusion-parameters.csv]
2026-10-02 Roll is trammed by shimming the shelf, not by oversizing the block holes
    The shelf was already a bearing joint - the file's own words, 'takes the vertical load
    directly in bearing rather than through bolt shear'. A shim belongs there. Slop does
    not belong in the four Y bearing blocks, which carry the whole gantry into the rails
    and which the repo's own close-fit rule says to keep tight.
    The 1in shim strip on hand is exactly the bar's 25.4 width, so a strip cut to the
    bar's 60 is a full-face shim. Slot it open at Y 15 and Y 45 to clear the vertical M8,
    so it slides in with those loosened rather than removed.
    Resolution is a non-issue: the 0.03 strip is worth 0.003 mm per 100 mm of tram. Ran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
    [fusion-parameters.csv]
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2026-10-03 Sheets 8, 9 and 10 go green: the X stations close and Sheet 9 re-datums
    X: first hole at 50, then 150 pitch, on all three plates - seven per row at
    50 to 950 with 50 clear at each end. The pitch had been written down for weeks;
    where the first one sat never had been, which is the whole reason those rows
    were amber rather than wrong.
    Sheet 9's Y now comes off the BOTTOM edge, and that is the better fix rather
    than the tidier one. The four T-slot rows were drawn 15/45/75/105 down from the
    top, which was right only if the plate finished flush with the Y beam's top
    face - and 304.8 is a BOUGHT 12in size, not a derived one, so nothing
    guaranteed it. Off the bottom they are 199.8 / 229.8 / 259.8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
    [fusion-parameters.csv]
2026-10-03 No channel: the plates sit ON the box and the tongues lap them from outboard
    This inverts the box footprint I recorded this morning, and the earlier reading
    was simply wrong. It had the box tucking INSIDE the plates at 1205.4 by 983.65.
    It does not - the machine stands on the box. The back and side plates sit FLAT
    ON THE TOP SKIN and the laminated tongues stand proud OUTBOARD of them, so the
    tongue's inner face is the plate's outer face and the box is the larger part.
    BOX_W 1205.4 -> 1211.75 = REAR_PLATE_L, the machine's outer envelope
    BOX_FORE_AFT 983.65 -> 1156.35 = 1000 beam + 6.35 rear plate + 10 fin + 140
    THE FRONT HAS NO TONGUE. The box runs BOX_FRONT_OVERHANG = 140 pa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
    [fusion-parameters.csv]
2026-10-03 The side tongue is 1000 long off a 1/4in offset, and that closes the fin clash
    His, 2026-10-03: SIDE_TONGUE_START 6.35 from the box's back edge, SIDE_TONGUE_L
    1000, so SIDE_TONGUE_END 1006.35. That is exactly the span of the Y beam and of
    the side plate the tongue laps, and the front fin caps the beam from 1006.35
    forward - so THE TONGUE ENDS PRECISELY WHERE THE FIN BEGINS.
    lateral-stiffness.md's open item wanted the side curb 'terminated short of the
    riser's station' because the fin stands FIN_PROUD = 16.825 outboard of the side
    plate, which is also the tongue's inner face: a tongue reaching that far forward
    would be held off the plate by the fin along the plate's whole length, losing
    the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
    [fusion-parameters.csv]
2026-10-03 Tongue is one 19 mm lamination - and that exposes a 2.175 conflict with the fin
    T_BOX_TONGUE = 19, his 2026-10-03. ONE lamination, not the two-at-38 the old
    walls had: with no channel there is nothing for a second one to form.
    He also said the front fins run past the side plate by 19, so the fin covers the
    side tongue's front end grain completely. THE REPO'S OWN CHAIN DISAGREES by
    2.175: FIN_PROUD derives to 16.825, being FIN_OVERHANG 20 less the 3.175 side
    plate, so 2.175 of end grain stays exposed.
    FIN_COVERS_TONGUE_END carries that as a derived -2.175 rather than me picking a
    side. Either FIN_OVERHANG is 22.175 rather than 20, or the end grain is short of
    covered. FIN_COL_OUTB, which FI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
    [fusion-parameters.csv]
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2026-10-03 The fin's 16.825 stands: partial end-grain cover is deliberate
    He confirmed the repo is correct - FIN_PROUD derives to 16.825 against a 19 mm
    tongue, so the fin covers all but 2.175 of its front end grain, and that is
    fine. The earlier '19 past the side plate' was the loose number, not the chain.
    FIN_COVERS_TONGUE_END keeps its -2.175 but its note now records the ANSWER
    rather than the discrepancy, so the next person reading it finds a decision
    instead of an open question. Nothing to change in any drawing.
    [fusion-parameters.csv]
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2026-10-03 Model fixes: fins are tapered end caps, plus view presets and an interference check
    THE FINS WERE IN THE WRONG PLANE. I had drawn them as flat plates on the Y
    beams' OUTBOARD SIDES. They cap the beams' FRONT ENDS - normal to fore-aft, the
    way the rear plate does at the back - with the taper facing INBOARD and the
    outboard edge square. His correction, and it needed real geometry rather than a
    box, so the generator grew a prism() that extrudes an X-Z profile along fore-aft.
    Added while chasing it, both worth keeping:
    - VIEW PRESETS (iso / front / back / left / right / top). I could not tell
    from the iso view whether the fins were drawn at all. They were - just
    hidden behind the rear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
    [make-3d.py]
2026-10-04 Rails and bearing blocks in the model - and the check found a 30 mm error of mine
    Added 16 parts: HGR20 rails and HGH20 blocks on both Y beams, across the X beam,
    and up the Z carriage, as their own toggleable group. Rails drawn as 20 mm
    SQUARE ROD - his call, recorded as RAIL_W with a note that the real profile is
    shorter than it is wide, so it is his approximation and not one the model
    invented. Z_RAIL_COL 57.5 lifted out of z-carriage.md where it had sat since
    2026-09-30.
    X HOME WAS AT THE WRONG END. My frame's X 0 is the rear plate's left seen FROM
    BEHIND, so the operator standing at the front has it on their RIGHT - and
    parking the carriage at min X put it back-right. Operator's left i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
    [fusion-parameters.csv]
2026-10-04 The Z spacer bars, which were missing from the model
    Two 2in bars, one per rail, sandwiched between the Z bearing blocks and the Z
    plate. He spotted the omission. The GAP was already correct - zp_back has always
    been cp_front + RAIL_STACK + SPACER_T - so nothing moved; there was simply
    nothing drawn in the 15.41 between the block face and the plate.
    New symbols SPACER_L 150.5 and SPACER_W 50.8. The length is recorded as a
    MEASUREMENT OF ONE BAR, not a design length, because its pair measures 151.6 -
    they were cut from one 12in piece and are 1.1 apart. Nothing is located by their
    ends, so that does not matter, but writing 150.5 as if both bars were that would
    have been a quiet lie.
    Interfer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
    [fusion-parameters.csv]
2026-10-04 The spindle is round now, and its two clamps hold it to the Z plate
    Added a cylinder primitive. A box misrepresented the barrel's clearance - at 45
    degrees a box corner stands r*(sqrt2-1) = 16.6 mm further out than the real
    dia-80 body does, which is the sort of thing that makes a clearance look tight
    when it is not. Barrel and collet nut are both cylinders now.
    Two clamps, CLAMP_CENTRES 116 apart about the Z plate's mid-height, each
    CLAMP_AXIAL 55 tall and CLAMP_W 122 across, reaching from the plate's face past
    the bore so the barrel runs through them. CLAMP_W 122 is new; it was already
    drawn on Sheets 3 and 4 as the 122 x 55 footprint but had never been a symbol.
    The spindle axis is now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
    [fusion-parameters.csv]
2026-10-04 Fin windows and the interposer - and they expose a 2.8 mm conflict
    The windows are cut in the fins now (real holes in the extruded profile, not
    painted on) and the interposer bars run under each Y beam and out through them.
    Stats moved behind a Show info button; the panel was covering the machine.
    The window geometry CONFIRMS ITSELF: at Sheet 1's drawn Y 20 the window's
    outboard edge lands on X 3.175 and 1208.575 in machine coordinates, which are
    exactly the two Y beams' outer faces - which is what Sheet 1's own note says it
    is aligned to. That also settles WINDOW_OUTB: the registry's measured 19 is
    stale against the drawn 20, and both are now in the registry saying so.
    🔴 THE INTERFEREN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
    [fusion-parameters.csv]
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2026-10-04 The M8 flange is a 2.5 dome, not a 5 mm disc - the repo had it wrong
    His correction 2026-10-03. gantry-beam-joint.md's measured table has carried
    '17.3 mm diameter, 5 mm high' since 2026-09-29 and the height was wrong: the
    flange is a DOME, 2.5 at the centre, falling to UNDER 1 at the 17.3 rim.
    FLANGE_HEAD_H goes 5 -> 2.5 and FLANGE_RIM_H is new at 1, recorded as an UPPER
    BOUND because he gives it as 'less than 1'. The rim figure is worth its own
    symbol: it is the one that matters for anything passing close to a bolted joint,
    where the centre thickness does not.
    What neither covers is the HEX HEAD sitting on top of the flange, which the repo
    does not dimension anywhere. So the 3D model is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
    [fusion-parameters.csv]
2026-10-04 M5 flange head 13.4 x 2.4 - and the repo's 11.8 was wrong too
    His measurements 2026-10-03. The repo had carried 11.8 for the M5 flange head
    diameter, recorded in y-beam-support.md as the figure a since-corrected edge
    check leaned on. 13.4 is 1.6 bigger.
    The same sentence also said 'an 18 mm M8 head'. The measured M8 flange is 17.3.
    Neither error changes that passage's conclusion - 12 mm against an 8.65 half-head
    still clears - but both were being quoted elsewhere as though measured, which is
    how a wrong number travels.
    FLANGE_HALF and FLANGE_M5_HALF are new and exist only to stop one specific
    mistake recurring: that passage once raised a false alarm by comparing a head
    DIAMETER against an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
    [fusion-parameters.csv]
2026-10-04 Button heads not hex, the 45 strips in the model - and a 0.65 foul on their bolts
    THE HEADS ARE FLANGED BUTTON HEADS WITH A HEX SOCKET IN THE MIDDLE OF THE DOME.
    I had written that a hex head sat on top of the flange; it does not. 2.5 (M8)
    and 2.4 (M5) are the TOTAL proud heights, so the model was already right and
    only the words were wrong. Struck from all three places that carried it.
    New FLANGE_DRIVE records the drive type as a fact, because it changes how a
    joint is assembled: a hex key needs AXIAL access but reaches into a narrow slot
    where a spanner never would - which is exactly the front strip's case, 45 mm
    between the bearing block rows.
    The three 45 mm front joining strips are mo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
    [fusion-parameters.csv]
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2026-10-04 The flange heads do NOT clash - but 1/4in has never been checked, only 4 mm
    He measured it on a real beam with rails and bearing blocks installed: the
    flange RIM passes under the block's overhang and fits. The machine is the
    authority, so the clash I reported is withdrawn.
    My check was wrong for a specific reason worth recording: it was LATERAL ONLY.
    The block has BLOCK_OVERHANG_CLEAR = 4.5 mm of relief under its overhanging
    wing - which gantry-beam-joint.md's bench table has carried since 2026-09-29 -
    and the model draws blocks as plain solids with no relief at all. A 2D edge
    comparison was never going to settle a 3D fit.
    🔴 BUT HIS MEASUREMENT WAS TAKEN WITH A 4 mm PLATE AND THE STRIP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
    [fusion-parameters.csv]
2026-10-04 The 45 mm front strip goes 1/4in -> 4 mm: it has to clear the block overhang
    His decision 2026-10-03 after measuring on a real beam: at 1/4in the strip's
    flange bolt heads hit the bearing blocks. The heads reach 23.65 from the seam
    against a block inner edge near 23, so the rim passes UNDER the block's
    overhang, and there is only BLOCK_OVERHANG_CLEAR = 4.5 of room there. At 4 mm it
    clears. At 6.35 it is 2.35 taller and it does not.
    New T_FRONT_STRIP = 4. The strip had been sharing T_BACK_JOIN_PLATE's 6.35, and
    separating them is the honest shape rather than bookkeeping: the back plate is
    sized for STIFFNESS, the front strip is sized by WHAT FITS UNDER A BLOCK. Two
    different constraints shou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
    [fusion-parameters.csv]
2026-10-04 Clearance under the bearing block is at most 6, not 4.5 - and that closes the loop
    His, 2026-10-03, stated as AT MOST 6, so it is recorded as an upper bound. The
    4.5 came from the 2026-09-29 bench table.
    THE 6 IS THE BETTER NUMBER BECAUSE IT PREDICTS BOTH MEASURED OUTCOMES:
    strip stack vs clearance 6 measured
    4 mm 5.00 clears by 1.00 fits
    6.35 7.35 OVER by 1.35 hits
    At 4.5 only one of them followed. The 4 mm case computed as a NEAR MISS - 5
    against 4.5 - while fitting in practice, and I wrote that up as 'the arithmetic
    does not close, trust the measurement'. That gap was the tell: a clearance
    figure which contradicts a measurement is the figure to doubt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
    [fusion-parameters.csv]
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2026-10-05 There is no curb: the word is retired, the member is the tongue
    His instruction, 2026-10-04: scrub any reference to a curb with respect
    to the side plates or the torsion box. Zero references remain outside
    three deliberate retirement notes.
    This is a rename, not a redesign, and outboard-plate.md had already done
    the hard part on 2026-10-03 under "THERE IS NO CHANNEL" - the plates sit
    flat on the box's top skin and the 60 mm proud outer lamination laps them
    from outboard on a plain bolted lap. That correction renamed the member
    to "tongue" in the places it touched and left "curb" standing in the
    sentences it did not, which is how one member came to have two names and
    why the dead idea kept l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
    [fusion-parameters.csv]
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2026-10-05 The corner cut, and the stock stops being a coincidence
    His, 2026-10-04, and the two halves are one decision.
    THE 1/2in PIECE HE HAS IS 304.5 x 154 - recorded as XEP_STOCK_L,
    measured, and 304.5 NOT the 304.8 that 12in would be. That is exactly the
    substitution the root README's $130 story warns about, so the measured
    number is the one in the registry.
    BOTH PLATES LOSE THE FAR-FRONT CORNER on a straight line ending at
    X 185.5, Y 154 - 2a from X 242.5, Y 60 and 2b from X 304.5, Y 60. Y 60 is
    forced: below it is the upper extrusion's end and the plate has to stay
    full length to cover it; above it the corner carries nothing.
    ON 2B THE CUT REPLACES THE STEP. That is the "one less cut" and it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
    [fusion-parameters.csv]
2026-10-05 The corner cut ends at X 188, not 185.5 - stop crowding the block
    His, 2026-10-04, same day the 185.5 went in. The cut's landing point on
    the front edge moves out 2.5 mm on both plates.
    What it buys, computed and not measured - the perpendicular distance from
    the cut line to the far-upper bearing block M5 at X 183.5, Y 133.5:
    2a 12.3 -> 14.2 mm
    2b 17.3 -> 18.8 mm
    So past a ~10 mm counterbore the tighter of the two keeps about 9 mm of
    material instead of 7. The 2.5 costs nothing: the corner it keeps is dead
    material either way, which is the whole reason the cut exists.
    CORNER_CUT_X_END carries the value and both sheets derive from it. The
    superseded 185.5 stays in its note and in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
    [fusion-parameters.csv]
2026-10-05 2b: the interposer is UNDER the casting, and X 242.5 is the beam top
    His correction, 2026-10-04. The sheet had the right two numbers and never
    said what they were measured from or why the interposer entered the sum,
    which left 259.0 and 277.0 as values to copy rather than a chain to check.
    Two facts the sheet was missing:
    X 242.5 IS THE TOP OF THE X BEAM'S UPPER EXTRUSION, and it is the datum
    both BF12 rows are measured up from. On this plate the beam top and the
    2a outline's end are the same point - XEP_TOP_ABOVE_BEAM is exactly 60 -
    which reads like a coincidence and is not one, so the registry now says
    so at TONGUE_BF12_ROW1_BARE.
    THE CASTING DOES NOT SIT ON THE BEAM. The 3/8in interpo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
    [fusion-parameters.csv]
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2026-10-05 The plate stock is 200 x 300, and 304.5 was never real
    He corrected it: the 1/2in plate for both X end plates is 200 x 300. The
    304.5 x 154 this repo recorded as measured stock does not exist.
    That number was load-bearing. Sheet 2b was built on it - the tongue's far
    end was "the stock's own end, uncut", TONGUE_TOP derived FROM it, and the
    "one less cut" reasoning rested on it. Every number past X 242.5 moved:
    XEP_STOCK_L 304.5 -> 300 measured, his
    XEP_STOCK_W new, 200 and it is where the doubler's 45 comes from
    TONGUE_TOP 304.5 -> 300
    TONGUE_H 61.975 -> 57.475
    TONGUE_EDGE_MARGIN 27.5 -> 22.975
    2b corner cut (304.5,60) ->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
    [fusion-parameters.csv]
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2026-10-05 "Datum" is gone from the whole repo, 50 uses in 14 files
    His: "I hate the word datum. It's in the same category as OFF. Obtuse
    unless you have a specific background." And he wrote the replacement
    himself - "Each plate only has one WCS origin for the holes to be
    drilled" - which is now the line in assembly.md, machining.md's section
    heading and drawings/README.md.
    NOT A FIND-AND-REPLACE. The word was carrying five different meanings and
    each needed its own plain English:
    the machining frame -> WCS origin
    a thing others are set from -> reference ("the machine is the
    reference, not the drawing")
    a height held across a long part -> height reference (t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
    [fusion-parameters.csv]
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2026-10-08 Regenerate the Fusion CSV and the index off the corrected registry
    Fusion holds a COPY of the parameters, so it goes stale like any other
    derived file - the CSV is the import source and it was still carrying
    12.7 and the 1211.75 that followed from it.
    Re-import it before touching the model: Modify > Change Parameters >
    Import.
    [fusion-parameters.csv]
2026-10-08 The fin square is 11 7/8in, so FIN_BASE_W is 199.625 not 200
    HIS PIECE, 2026-10-07: the one square both front fins are cut from is
    11 7/8in = 301.625, not the 302 this was carried at as "measured". It had
    already been corrected once, away from a nominal 12in.
    Contained - it moves exactly two symbols, because nothing is laid out
    from the base width:
    FIN_STOCK 302 -> 301.625
    FIN_BASE_W 200 -> 199.625
    The taper is therefore 100 to 199.625 over 301.625, both halves still
    identical by rotation with FIN_KERF's 2 between them.
    [fusion-parameters.csv]
2026-10-08 Sweep the prose and the shop pack onto the corrected registry
    154 replacements across twelve hand-written files, then every derived
    file regenerated. These nineteen literals were each verified to be ONE
    quantity everywhere they appear before any of them was touched:
    1211.75 -> 1210.73 rear plate length and box width, same number
    1085.4 -> 1084.38 Y beam gap
    1205.4 -> 1204.38 beam span
    98.7 -> 98.19 sole bracket length
    73.3 -> 73.81 sole bracket free reach
    72.7 -> 72.19 X offset to the screw axis
    92.7 / 52.7 nut bolt rows
    21.3 -> 21.81 clear air past the doubler
    19.05 -> 18.285 R1-R4 into the doubler's edge
    80.875 and the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
    [fusion-parameters.csv]
2026-10-08 Both steel plates are ordered 11 7/8in, and the fin's base is the reference
    HIS CALLS, 2026-10-07. Two separate decisions landing on one number:
    THE FIN'S BASE IS THE REFERENCE. The base is the end that bolts down and
    bears, so it keeps the round 200 and the top absorbs whatever the square
    leaves. The registry now says that structurally rather than in prose -
    FIN_BASE_W is a fixed 200 and FIN_TOP_W DERIVES at 99.625. It was the
    other way round, which meant the square's 0.375 shortfall was landing on
    the bearing end.
    SIDE_PLATE_H and REAR_PLATE_W are 301.625, the ordered 11 7/8in - the
    same buy as the fin square.
    SIDE_PLATE_PROUD IS NOW NEGATIVE, -0.375. The side plate finishes just
    below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
    [fusion-parameters.csv]
2026-10-08 T_OUTBOARD_PLATE becomes an alias of T_SIDE_PLATE
    Two symbols for one piece of steel, and only one of them wired up.
    T_SIDE_PLATE carried 3.175 and fed sixteen symbols; T_OUTBOARD_PLATE
    carried the identical 3.175 and fed nothing.
    THE TRAP WAS WHERE TOMORROW'S MEASUREMENT WOULD HAVE LANDED. The standing
    instruction in gantry-beam-joint.md said "measure the delivered sheet
    (T_OUTBOARD_PLATE is nominal)" - and a caliper reading written there would
    have changed nothing. Not the rear plate's length, not the box width, not
    Sheet 7's hole columns. The prose now names T_SIDE_PLATE and says why.
    Same shape as T_DOUBLER earlier today, which was the same mistake about
    the end plate's offcut.
    EXERCI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
    [fusion-parameters.csv]
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
